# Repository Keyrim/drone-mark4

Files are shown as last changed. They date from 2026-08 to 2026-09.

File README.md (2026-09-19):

# drone-mark4 - "throw-drone"






A 5-inch racing drone is thrown by hand, motors off. The firmware detects the
throw, predicts the apex of the parabola, spins the motors up ahead of time,
recovers from an arbitrary attitude (the drone may tumble) and settles into a
stable hover. Everything is rewritten from scratch - firmware, simulator,
tooling - as a deliberate learning project. Behavioral reference: ArduPilot's
"Throw Mode".

Documentation:

- [API reference](https://keyrim.github.io/drone-mark4/) - Doxygen over the C++ of every node plus these pages, published from `main`
- [docs/architecture.md](docs/architecture.md) - system architecture (diagrams)
- [docs/plan-dev.md](docs/plan-dev.md) - development plan and reference document
- [docs/contributing/cpp-guidelines.md](docs/contributing/cpp-guidelines.md) - C++ coding guidelines
- [docs/mobile-app.md](docs/mobile-app.md) - phone as gateway: what the two mobile PoCs established, and the roadmap of `software/mobile`
- [docs/comm-design.md](docs/comm-design.md) - communication stack: transport presence, messaging postman, pull discovery, and the services on the messenger (issues #29 and #31)
- [worktrees/README.md](worktrees/README.md) - git worktrees: where they live, how to bring one up, build it, open it, remove it

## Modules

- `flight-core/` - pure flight core: no dynamic allocation, no
  exceptions/RTTI, no clock access. `float` everywhere
  (`-Wdouble-promotion` as an error).
- `platform/` - 3 abstract services (AbsSensorSource, AbsMotorSink,
  AbsClock) plus one implementation set per variant; commands come in
  through the `messaging` component, not through a platform service. No singletons: each executable has an
  explicit composition root in its main.
- `protocol/` - one protobuf schema (`mark4.proto`), codecs generated at
  build time for C/C++ (nanopb) and GDScript (godobuf); spoken by
  everyone (firmware, sim, Godot, hub).
- `telemetry/` - the registry of named measures a node exposes, declared
  next to the variables they read. A leaf: names, units and pointers, no
  wire. A ground tool discovers the list and streams the subset it wants.
- `transport/` - the interface manager: frames every payload with a source
  and a destination node, learns every node it hears, relays between links.
- `log/` - one logging module per source file, filterable at runtime, its
  lines going out on the wire like everything else.

## Build

### Inside the devcontainer (recommended)

Open `drone-mark4.code-workspace` in VS Code -> "Reopen in Container". The
workspace exposes the repo root and `software/` (the CMake project root) as
folders and carries the debug configurations. Both toolchains (native gcc +
arm-none-eabi) and the pinned tooling live in the image.

```sh
# Desktop: build + tests
cmake --preset desktop && cmake --build --preset desktop && ctest --preset desktop

# Sanitizers (ASan/UBSan)
cmake --preset desktop-san && cmake --build --preset desktop-san && ctest --preset desktop-san

# STM32F405 cross-compilation (Cortex-M4F) -> firmware.elf
cmake --preset stm32 && cmake --build --preset stm32

# Sign of life (runs its loop with or without a plant, no frame limit by default)
./software/build/desktop/drone_sim/drone_sim
```

### Mobile app (Flutter, Android)

`software/mobile/` is the Flutter project; the image carries Flutter, the
Android SDK, the NDK and adb. The phone is reached over Wi-Fi (developer
options -> wireless debugging), the container being on the host network:

```sh
./scripts/adb_wifi.sh                     # discovers the phone over mDNS, pairs once, connects
cd software/mobile && flutter pub get && ./tool/gen.sh   # generated codec, wire hash
flutter run                               # or: flutter build apk --debug --target-platform android-arm64
```

### Manual build (outside the container)

Prerequisites: CMake >= 3.25, Ninja, gcc, arm-none-eabi-gcc (ARM tarball
14.2.rel1), clang-format/clang-tidy 21 for the checks. Same commands as above.

### Code quality

```sh
git ls-files '*.cpp' '*.hpp' '*.c' '*.h' | xargs clang-format --dry-run --Werror
run-clang-tidy -p software/build/desktop "$(pwd)/(apps|flight-core|platform|protocol|tests)/"
```

## Simulation chain

Three processes are transport nodes on udp/47820 and find each other by
the transport's keepalives; the plant and the hub then ask every node that
appears who it is. The Godot plant spawns one virtual drone per node that
answers `drone_sim` and feeds it sensor frames in lockstep, `drone_sim` answers with
actuator frames and streams its status, logs and telemetry to the nodes
that subscribed, the hub decodes it for the pages. Nothing is configured,
start them in any order.

```sh
# Terminal 1 - flight process (one per virtual drone wanted)
./software/build/desktop/drone_sim/drone_sim

# Terminal 2 - the plant (the desktop build generated its codec)
godot --path sim-godot

# Terminal 3 - decoding endpoint and web pages on http://127.0.0.1:47810
./software/build/desktop/hub/hub
```

Every python tool in the repository runs on the standard library alone, so
there is nothing to install first.

## Debugging from VS Code

`drone-mark4.code-workspace` provides:

- `drone_sim (gdb)` - debugs the CMake launch target: pick the `desktop`
  preset and the `drone_sim` target in the CMake Tools status bar, the
  target is rebuilt automatically before each launch;
- `sim_stub (python)` - streams frames until stopped.

The default build task (Ctrl+Shift+B) builds the active CMake configure
preset.

## CI

- `devcontainer-image.yml` - reusable workflow that tags the image by a hash
  of the Dockerfile, builds and pushes it to GHCR
  (`ghcr.io/keyrim/drone-mark4-devcontainer`, public) only when that tag is
  missing, and retags `:latest` on main.
- `ci.yml` and `docs.yml` each call it as a first `image` job and run every
  other job inside the digest it returns, so a Dockerfile change is built and
  tested inside the PR that makes it, with no digest to bump by hand. `ci.yml`
  has 8 parallel jobs: desktop+tests, stm32, esp32, desktop-san, pages,
  mobile (gen, flutter analyze, format, test, debug apk), clang-format+ascii,
  clang-tidy.

## J-Link license note

The development image downloads the J-Link tools from segger.com: the
automated download (`--post-data accept_license_agreement=accepted`) implies
acceptance of the [Segger license](https://www.segger.com/downloads/jlink).
If that is a problem, comment out the J-Link layer in the `Dockerfile` or
install the .deb manually. The whole J-Link stack (`JLinkExe`,
`JLinkGDBServer`, `JLinkRTTClient`) runs inside the container: the probe is
attached to WSL with `usbipd` and reaches the container through the `/dev`
bind mount (see `docs/bring-up.md`).

## License

[MIT](LICENSE).

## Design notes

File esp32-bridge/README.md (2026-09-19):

# ESP32 relay

Firmware for the ESP32-C3 SuperMini (IPEX variant) riding the drone, wired
to the flight controller's UART. It is a transport relay
(`software/components/transport/`): one transport node with two links, the
board's UART and the WiFi LAN, forwarding frames between them. It is a node
of the system like any other: present on both links through the
transport's keepalive, answering an `IdentityRequest` with its own
`Announce` like every other node, and it logs through the
project's log library. From the LAN's point of view the board and the relay
are two nodes on udp/47820 sharing one address, exactly like `drone_sim` is
one; the hub has no path, port or click specific to either. It updates
itself over the air from the hub's update panel, like the flight
controller does (see "Over-the-air update" below).

## What crosses, and what does not

The relay forwards with the transport's generic rules alone (split
horizon, one hop less per relay, duplicate drop by `(src, seq)`); every
transport node relays, and this one is the only node with two links:

- towards the LAN: everything the board emits (its `Status` stream, its
  telemetry samples, its log lines, its answers), each a unicast to the
  node that asked or subscribed, plus its keepalives;
- towards the UART: every unicast the transport routes there (the board is
  the only node on that link, so a unicast routed there is for it: RC,
  tuning, subscriptions, updater messages), and the LAN's keepalives, which
  are the only broadcasts left. The line is 921600
  baud and `UartStream::write` refuses a frame the TX ring cannot hold
  whole, so a LAN that sends the board more than the line carries degrades
  by dropping, never by blocking.

What the relay says itself travels the same way: its keepalive is a
broadcast on both links like any node's, its log lines and its module
table go to whoever asked for them.

Nothing relayed is decoded. What the delivery hands to the relay itself
goes to its `Messenger` (`software/components/messaging/`), which decodes
it once and calls the one handler that claimed its body tag; a message no
handler claimed is counted and dropped. Four handlers claim something
here: `LogProvider` (the line subscription, the module table, the level
moves), `Commands` (`Reboot`), `Discovery`
(`IdentityRequest`) and `OtaProvider` (the six `Ota*` requests).

## Composition

`main/bridge_main.c` brings the network up (unchanged: STA on the network
named in `local.cmake`, or the `mark4-bridge` access point after ten seconds
without an address) then hands over to `relayRun()` in `main/relay.cpp`:

- `UartStream`, an `AbsByteStream` over the ESP-IDF UART driver rings
  (`uart_read_bytes` with a zero timeout, `uart_write_bytes` only when the
  transmit ring has room for the whole frame, refused and counted
  otherwise), wrapped in the shared `UartLink` (serial framing
  `A5 5A len16 payload crc16`);
- the shared `UdpLink`, compiled as is against lwIP's BSD socket API
  (shared discovery port 47820 with `SO_REUSEADDR`, ephemeral data socket,
  broadcast to 255.255.255.255 with `SO_BROADCAST`). lwIP has no
  `getifaddrs()`; the relay hands its own address to
  `UdpLink::addLocalHost()` so its broadcasts coming back are dropped as
  echoes;
- `Transport` with node id `hashNodeId()` of the WiFi MAC; it relays
  between its two links as any transport node with several links does;
- the shared `Messenger` over it: the one caller of `Transport::poll()`,
  the one decoder and the one encoder of this node;
- `LogProvider` (`software/components/log/`), this node's log on the wire:
  the lines to whoever subscribed, the module table one page per request,
  the levels;
- `Commands`, the handler of what is left of the node's own: the `Reboot`
  that ends an update session, announced on the radio before the reset;
- `Discovery` (`software/components/discovery/`) with the identity built
  by `relayIdentity()`: kind `RELAY`, name `relay-<the low three bytes of
  the WiFi MAC>`, mcu `ESP32C3`, the build epoch and short commit hash the
  top-level `CMakeLists.txt` stamped in, and the wire hash. It answers an
  `IdentityRequest` and nothing else: this node asks nobody who they are,
  so it carries no directory;
- `FirmwareStoreEsp32` (`main/firmware_store_esp32.cpp`) over the two OTA
  partitions and the shared `OtaUpdater` (`ota/updater.hpp`) on top of it,
  served on the wire by the shared `OtaProvider` (`ota/provider.hpp`) over
  a `RelayOtaGate` that arms
  nothing and watches no pack voltage: the update session, fed by the
  `Ota*` unicasts a hub addresses to the relay. A flash that is not laid
  out for two slots leaves the provider unbuilt, so no handler claims the
  `Ota*` tags at all and every request is refused;
- the log library: the shared `ConsoleSinkPosix` (its console is plain
  stdio) next to the `LogProvider` above, the two sinks every line goes
  to. The clock is `esp_timer_get_time()`. The bring-up in `bridge_main.c` is C and
  speaks through two shims, `bridgeLogInfo()` / `bridgeLogWarn()`, rather
  than being ported to C++: the smaller diff of the two.

The main task polls the messenger once per FreeRTOS tick (1 ms,
`CONFIG_FREERTOS_HZ=1000` in `sdkconfig.defaults`): one frame is one
datagram, no aggregation. Every poll drains both links whole; a 160-byte
telemetry frame takes 1.7 ms on the line, so the added latency is under one
frame time either way. The UART driver keeps 4096 bytes on the way in
(about 44 ms of a full line, what a WiFi stall may cost before bytes are
lost and the framing resynchronizes) and 1024 on the way out.

The shared sources are compiled by the ESP-IDF build straight from
`software/components/`: `transport.cpp`, `uart_link.cpp`,
`posix/udp_link.cpp`, `messaging/src/messenger.cpp`,
`discovery/src/discovery.cpp` (the answer alone: `discovery_directory.cpp`
stays out, this node asks nobody), the log library (`module.cpp`,
`wire.cpp`, `provider.cpp`, `posix/console_sink_posix.cpp`) and the
header-only `ota/` bricks in the `main` component, the nanopb runtime,
`envelope.cpp` and the codec generated from
`software/components/protocol/mark4.proto` in `components/mark4_proto/` (same generator, same pinned nanopb commit, same
`PB_NO_MALLOC PB_BUFFER_ONLY` as the desktop build; the generator needs a
python with `protobuf` and `grpcio-tools`, the component uses the first of
the IDF interpreter and `/usr/bin/python3` that has them). The `main`
component carries the project's warning set (`-Wall -Wextra -Wconversion
-Wdouble-promotion -Werror`) and `-fno-exceptions -fno-rtti`.

## Logs

Five modules, ids from `main/log_modules.hpp` (256 up, the shared code
takes its own from `log/module_ids.hpp`): `app/boot`, `app/wifi`,
`relay/core`, `relay/stats`, `relay/ota`; the firmware store logs as the
shared `ota/store`. Every line goes to the USB Serial/JTAG console
(115200) and, once a node has subscribed to this one's lines, onto the LAN
as a `Log` envelope addressed to it. What a healthy relay prints:

```
00:00:01.712 INFO app/wifi: joined <ssid> as 192.168.1.31   (or: access point mark4-bridge)
00:00:01.760 INFO app/boot: boot: node ff42bd55 relay build 1756512000 953448a1 wire 4f2c81de
00:00:01.760 INFO app/boot: uart 921600 baud, lan data port 60278, discovery port 47820
00:00:02.140 INFO relay/core: node 6c41b2f0 up on the uart              (the board)
00:00:02.900 INFO relay/core: node 1cd5e199 up on the lan at 192.168.1.13:41283   (the hub)
00:00:12.010 INFO relay/core: node 1cd5e199 gone                        (3 s of silence)
```

`relay/stats` is the five-second counters line, at DEBUG so it is off by
default; a client turns it on with a `LogSetLevel` carrying the id of
`relay/stats` and `DEBUG`, addressed to the relay's node id (the hub's
pages list its modules like any node's), and it starts arriving as `Log`
messages:

```
00:00:20.000 DEBG relay/stats: nodes 2, relayed 1063, dropped 0, uart tx full 0
```

`relayed` counts frames forwarded (one per link for a broadcast),
`dropped` the transport's drops (unknown destination, hops exhausted),
`uart tx full` the frames the UART ring could not take whole. The timestamps are the module's uptime.

## Network

The network to join is named in `esp32-bridge/local.cmake`, which is untracked
because credentials belong to whoever builds:

```cmake
set(BRIDGE_STA_SSID "my-network")
set(BRIDGE_STA_PASSWORD "my-password")
```

Without that file the relay is an access point (`mark4-bridge`, WPA2,
192.168.4.1, see `bridge_main.c`) and nothing else. Either way the only port
in play is udp/47820, the transport's discovery port; the relay's data
socket takes an ephemeral port that the hub learns from the board's frames.
A station that loses its network keeps asking to join it back, and the
`UdpLink` tries the global broadcast again on every send, so a network that
comes back is used again without a reset.

## Wiring

| ESP32-C3 | Flight controller  |
| --- | --- |
| GPIO3 | UART TX (board out)|
| GPIO4 | UART RX (board in) |
| GND | GND |
| 5V | UART connector +5  |

921600 baud, 8N1, no flow control. The console stays on the USB Serial/JTAG
port of the module, which is why `sdkconfig.defaults` moves it off the UART
pins.

## Build and flash

The dev image ships ESP-IDF (see `.devcontainer/Dockerfile`); `idf.py` is on
the PATH and needs no `source export.sh`. From the repository root:

```sh
idf.py -C esp32-bridge build                       # -> build/esp32_bridge.bin and .ota
idf.py -C esp32-bridge -p /dev/ttyACM0 flash monitor
idf.py -C esp32-bridge fullclean                   # wipe build/
```

The build identity the boot line reports (build epoch, short commit hash)
is read by CMake at configure time, so a plain rebuild keeps the previous
pair; `idf.py -C esp32-bridge reconfigure` refreshes it. The same pair is
stamped into the image as `PROJECT_VER` (`<buildEpoch>-<gitHash>`, the
version field of the ESP-IDF application description) and into the
manifest of `build/esp32_bridge.ota`, the bundle the hub sends: the
identity a slot reports and the one a bundle announces are the same value.

The USB flash is needed once per module, to lay the flash out
(`partitions.csv`: `nvs`, `otadata`, `phy_init`, then the two application
slots `ota_0` and `ota_1` of 1984 KB each on the 4 MB flash) and to put the
first image in `ota_0`. Every later image arrives over the air.

`fullclean` keeps `sdkconfig`, so a change to `sdkconfig.defaults` only lands
after `rm esp32-bridge/sdkconfig` (or `idf.py -C esp32-bridge set-target ...`
for the target itself).

`sdkconfig.defaults` pins the `esp32c3` target, the console, the tick rate,
the 4 MB flash, the custom partition table and the bootloader's rollback,
and is the only tracked configuration; `sdkconfig` and `build/` are
generated. The port is whatever the board enumerates as once attached to WSL
with `usbipd` (`/dev/ttyACM*` for the native USB serial of the C3,
`/dev/ttyUSB*` behind a USB-serial chip).

## Using it from the hub

Nothing to do: the board shows up in the hub's discovery like `drone_sim`
does, and the Connect button of its row is the same. The relay sits next to
it as a `relay` node at the same address: nothing to click, a place to read
its logs and turn `relay/stats` on.

## Over-the-air update

The relay runs the update system of `docs/ota-design.md` (section 8) as
one more node: the same `OtaUpdater` as the flight controller, the same
`Ota*` messages, the same hub panel. What differs is underneath and is the
store's business (`main/firmware_store_esp32.cpp`):

- the two slots are the `ota_0` / `ota_1` partitions (slot A / slot B),
  and in place of the flight controller's metadata log the store reads and
  writes what the ESP-IDF bootloader keeps in `otadata`: a staged image is
  `esp_ota_set_boot_partition()`, the self-confirmation of a trial image on
  its first ground contact is `esp_ota_mark_app_valid_cancel_rollback()`,
  a revert points the bootloader at the other slot. With
  `CONFIG_BOOTLOADER_APP_ROLLBACK_ENABLE` the IDF bootloader boots a new
  image exactly once as pending-verify and rolls back on the next reset if
  it was never confirmed: the one-shot trial of the design, implemented by
  IDF;
- the image is a raw ESP-IDF application image, verified before staging
  with IDF's own `esp_image_verify()` and matched against the announced
  length; its identity is the `PROJECT_VER` above;
- the bundle holds one image for both slots (an IDF image is
  position-independent across OTA partitions), packaged by
  `scripts/make_ota.py --esp32` at the end of every build.

From the hub's update panel: pick the relay node, type the bundle path
(`esp32-bridge/build/esp32_bridge.ota`, the default being the flight
controller's bundle) and click update. The erase of a 1984 KB slot takes a
few seconds, in 64 KB blocks with a yield between two so the task watchdog
stays quiet; the relay relays nothing meanwhile, which the design accepts
(the drone is on the ground when its radio gets reflashed). The transfer
runs over UDP directly, so the UART budget does not apply: a 870 KB image
is on the far side in seconds. The relay then answers the `Reboot`,
`relay/ota` logs the request, and the new image comes up; the first
`OtaStatusRequest` it serves confirms it.

A relay still on the old single-app layout logs `no two-slot partition
table` at boot and relays as before; it needs the USB flash above once.

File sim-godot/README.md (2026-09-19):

# Godot simulator

Standalone Godot 4.4 project (GDScript only) that plays the role of the
drones and their environment: rigid bodies with a motor model, realistic
sensor models, and a transport node that talks to the flight processes. It
runs on the HOST, not in the devcontainer, and it never links flight-core:
it only speaks the wire of `software/components/protocol/mark4.proto`,
through the GDScript codec the desktop build generates into `scripts/gen/`,
inside the frames of `software/components/transport/` (see "Transport").

The plant is one node of the LAN, kind `plant`, and hosts **one virtual
drone per `drone_sim` node it hears**: a flight process that starts is
heard, asked who it is, and gets a drone spawned on the ground for it once
its identity says `DRONE_SIM`; a flight process that dies has its drone
removed once its node expires. Each virtual
drone sends what an IMU and a barometer would measure to its own flight
process, receives the four motor commands that process decides, and
applies them as forces. Nothing else crosses the boundary.

## Run

1. Install Godot 4.4 or newer (standard build, no C# needed). The project
   already selects Jolt Physics and a 500 Hz physics tick, there is nothing to
   configure. It also pins the engine's worker pool to one thread
   (`threading/worker_pool/max_threads`): Jolt dispatches every step to that
   pool, and at 500 steps per second the wake-ups of a dozen threads cost
   more than the step itself (about 750 us against 85 us per step on a 12
   core host, the difference between 30 and 60 fps with one drone).
2. Start one flight process per drone wanted, in the container, in any
   order relative to this project (each one is a transport node on
   udp/47820 and keeps alive once per second):

   ```sh
   ./software/build/desktop/drone_sim/drone_sim
   ./software/build/desktop/drone_sim/drone_sim   # a second drone, optional
   ```

3. On a fresh clone, import the project once so Godot generates its cache
   (`.godot/` is not committed; without it the global script classes are
   unknown and every script fails to parse). Opening the project in the
   editor does it too.

   ```sh
   godot --path sim-godot --headless --import
   ```

4. Run the simulator. The Godot binary is both the editor and the runtime;
   the command line decides which one you get:

   ```sh
   godot --path sim-godot        # run the main scene directly, no editor
   godot -e --path sim-godot     # open the project in the editor (F5 to run)
   ```

The overlay is four cards around the view. Top left, the plant: its node
id, the wire hash this build speaks, how many drones it hosts, the frame
rate. Top right, the drones, one row each (flight process node id, phase,
altitude); the followed one is highlighted and a click on a row follows
it. Along the
bottom, the followed drone: its phase as a colored pill, the node id of
its flight process, the simulated time, the four motor commands as bars
(the marker on each bar is the effective speed after the motor lag), the
altitude, the accelerometer magnitude in g, the throws detected, the IMU
and barometer validity, the RC link state, and the packet counters of the
link. Bottom right, the camera mode and the keys. A toast announces a
flight process joining or leaving. With no flight process on the LAN the
world is empty and the overlay says so.

The phase, the throw count, the validity flags and the RC state come from
the `Status` each flight process streams to this plant because the plant
subscribed to it, and which the plant reads (and nothing else: it acts on
none of it). A drone that has not reported for a
second shows `no status`. The same phase colors the status light on the
rear of each drone model, which blinks while the flight process reports
its RC fail-safe active; a ring on the ground marks the followed drone,
and every drone leaves a fading trail of the last three seconds of its
path in the air.

Every sensor frame also carries the exact state (attitude, position,
velocity, no sensor model) as `PlantTruth`; the flight process forwards it
inside its telemetry, so the attitude page served by the hub draws the
estimated attitude against the exact one, per drone. Wire vectors use the
drone frame convention of the wire (body x forward, y left, z up); the
remap from the Godot axes happens in `sim_link.gd`.

## Controls

The keys and the mouse only drive the view: which drone is looked at, and
from where.

| Input | Effect |
| --- | --- |
| `TAB` | follow the next drone, in spawn order |
| click | follow the drone under the cursor |
| `C` | next camera mode |
| wheel | zoom the chase and follow cameras |
| `ESC` | quit |

Four camera modes, cycled with `C` and remembered per drone:

- **chase**: trails the drone from a fixed world offset. The offset is in
  world axes on purpose, so the view stays readable while the drone
  tumbles: the mode for a throw.
- **follow**: behind and above the drone, aligned on its heading (yaw only,
  never its roll or pitch): the third person view of a piloted flight. A
  drone entering a piloted phase pulls a chase camera into this mode once,
  unless a mode was chosen by hand for it.
- **los**: the camera stands where a pilot would (a fixed spot on the
  ground, 7 m back at eye height) and turns to keep the drone in sight,
  its field of view tightening with the distance: what a line of sight
  flight actually looks like.
- **fpv**: rides the drone, tilted up like a flight camera.

Nothing here touches a drone. This project is the plant, and it holds no
pilot state at all: the kill switch, the arm switch and the throttle are
RC, they belong between the cockpit and the flight process, and they never
pass through here. Resets and throws are scenarios (next section) that the
console page served by the hub and the mobile app send to the flight
process, which forwards them to its drone here: one door for the console
and the phone, and no key of this project on the body.

Piloting flows through the hub or the phone: an `rc` message aimed at
`drone_sim` is the same packet and fail-safe a real flight uses (200 ms of
silence trips the kill), which is exactly the path worth exercising. When
the kill switch is engaged the flight process answers with four zeros and
the motors spin down with their normal lag.

## Scenarios

A scripted run arrives as a `SimScenario` envelope, unicast by the flight
process to this plant: the flight process received it from the hub,
its messenger handed it to its plant link, and the plant forwards it to
the virtual drone that belongs to it, as its own message. One scenario is one run. It opens with a
reset - teleport, reseed every generator, clear the hand - and everything
it asks for afterwards
(the throw, or the grab and the swing) is scheduled from that reset tick, on
this project's own tick grid. Nothing outside has to agree on which absolute
tick a run began at, and nothing carries over from the run before.

A block is played once per change of its `sequence` byte, so a sender may
resend it freely: the lockstep handshake already guarantees the block gets
here, since a tick is not complete until its reply arrives.

## Physics

- Mass 0.65 kg, inertia set by hand to (0.0023, 0.0040, 0.0023) kg*m^2 in the
  body frame (y up), damping disabled, sleeping disabled.
- Four motors on a 45 degree X layout, 0.08 m from the center of mass,
  numbered like a 4 in 1 ESC: 0 rear right, 1 front right, 2 rear left,
  3 front left. Diagonal pairs spin in opposite directions.
- Each motor follows its command through a first order lag of 25 ms, then
  produces `6.0 N * w^2` of thrust along the body y axis and a yaw reaction
  torque of `0.012 N*m * w^2`, with `w` the lagged command in [0, 1]. Four
  motors at full speed give 24 N against 6.4 N of weight, about 3.7:1.
- A linear air drag of `-0.05 N/(m/s) * v` keeps ballistic trajectories
  plausible without pretending to model a real drag polar.
- An instant throw is a constant force applied for 120 ms (the exported
  `throw_duration_s`), sized so the velocity increment matches the release
  velocity of the scenario, plus an angular momentum impulse for its release
  spin. Gravity keeps acting during those 120 ms, so the release velocity is
  slightly lower than the requested increment. Nothing is faked in the
  sensors: the thrust phase and the free fall that follows are what the
  rigid body actually does.

## Sensors

Sampled once per physics tick, in this order for every channel: ideal value,
constant bias, gaussian noise, clipping to the full scale, quantization to the
LSB of a 16 bit converter.

- **Accelerometer**: specific force in the body frame, not coordinate
  acceleration. It is computed from the velocity delta of the physics step,
  `f = (v - v_previous) / dt - g`, rotated into the body frame. Contact forces
  are therefore included for free: the reading is +1 g upward while sitting on
  the ground, exactly 0 in free fall, and a few g while the hand accelerates
  the drone. Full scale +/- 16 g.
- **Gyro**: body angular rates, full scale +/- 4000 deg/s, which a tumbling
  throw can approach.
- **Barometer**: standard atmosphere,
  `p = 101325 * (1 - 2.25577e-5 * h)^5.25588`, plus noise.

Noise standard deviations, bias spread and the generator seed are exported on
the `Sensors` node. The generator is seeded explicitly and the biases are drawn
once at startup, so the same seed replays the same sensor stream.

## Transport

`scripts/transport/transport.gd` (`Mark4Transport`) is the GDScript port
of `software/components/transport/`, the same frames and the same rules:
an 11-byte little-endian header (`src u32, dst u32, seq u16, flags:hops
u8`, the hop count on the low nibble and the keepalive flag on bit 7)
in front of every payload, a node table learnt from every frame heard
(address, last sequence, boot id, received / lost / duplicate counters,
3 s expiry, `node_up` / `node_down` signals), presence as a keepalive - a
flagged frame carrying the sender's boot id, broadcast every second and
unicast once to every newcomer, never delivered upward whatever it carries
- duplicates dropped by `(src, seq)`. A keepalive whose boot id is not the
one held is another run of the same node id: the transport takes that node
down and up again, so the drone it hosts starts over instead of believing
it is still subscribed. An empty payload handed to `send()` is refused. No
relay, so every frame it sends carries `hops` 0.
The node id is a random nonzero `u32` drawn at start.

Sockets, as in the C++ `UdpLink`: one shared discovery socket on
udp/47820 (`--discovery-port N` after `--` for an isolated pair) that receives
the broadcasts of the LAN, and one ephemeral data socket every frame
leaves from, so its source port is this node's unicast address. Godot's
`PacketPeerUDP.bind()` sets no reuse option and refuses a port another
process already holds, so the discovery socket is a `UDPServer`: its
`listen()` sets `SO_REUSEADDR`, which Linux honours for UDP next to the
`SO_REUSEADDR + SO_REUSEPORT` pair the C++ link sets, and the hub, the
flight processes and this plant share udp/47820 on one host. The server
hands datagrams out as one `PacketPeerUDP` per remote address; the
transport keeps them and drains them all on every poll. Broadcasts go to
`255.255.255.255`, and to `127.255.255.255` when the host has no route
for the former, like the C++ link.

`scripts/transport/announce.gd` builds this plant's identity (an
`Announce` of kind `PLANT`, name `godot-plant`, mcu `SIM`, the wire hash of
the generated codec) and keeps the body tags a payload is told apart by,
after one look at its first bytes: every payload addressed to this node
goes through one handler, the lockstep actuator frames of every drone it
hosts at 500 Hz included, and the codec never runs on a frame it does not
want.

`scripts/transport/discovery.gd` (`Mark4Discovery`) is the GDScript port
of `software/components/discovery/`, both directions of "who are you":
every node the transport learns is asked with one `IdentityRequest`, sent
again every 500 ms up to 5 times before the node is left mute, and the
`Announce` that comes back is kept as that node's identity and reported on
the `identity` signal; an `IdentityRequest` addressed to this plant is
answered with its own `Announce`, unicast to whoever asked. Nothing is
broadcast and nothing is unsolicited: presence is the transport's
keepalive, identity is asked for.

`scripts/transport/requests.gd` (`Mark4Requests`) is the port of the
request side of `software/components/messaging/`, the one place this node
numbers, resends and acknowledges. A message that has to arrive travels as
a request: it carries a `request_id` of this node's own counter (field 100
of the `Envelope`, never 0), it is kept encoded and sent again every 500 ms
up to 5 sends by default (the policy is per call), and the `RequestAck`
carrying the same id completes it; out of sends, or when the destination
goes down, the request is dropped and `request_failed` says so. The other
direction is automatic: every payload this plant receives that carries a
non-zero id is answered with a `RequestAck` at once, whatever it is and
whether or not anything here reads it. That answer is built from the first
bytes of the payload, so it costs no decode and does not depend on the
order the listeners of `payload_received` were connected in. Stream data
(the `Status`, the lockstep frames) carries no id and is never
acknowledged: a sample is only worth its own instant.

`scripts/transport/status_consumer.gd` (`Mark4StatusConsumer`) is the
consumer of that stream. A flight process emits its `Status` to the nodes
that asked for it and to nobody else, so the plant sends one
`StatusSubscribe { enabled: true }` per drone it spawns, as a request, and
reads the answer the flight process sends back: the same message as
applied, `enabled` false when it has no room for one more subscriber. The
drone that leaves the world is told to stop the stream, unless its node is
already gone, in which case it forgot its subscribers when it left. There
is nothing to configure in the subscription: what the stream carries and
how often it comes are states of the flight process.

`scripts/drone_manager.gd` (`DroneManager`, the `Drones` node of the main
scene) owns the transport, the request helper and the directory and drives
the three once per physics tick, before the drones run. An identity of
kind `DRONE_SIM` spawns `scenes/drone.tscn` for that node, on a 1 m grid
(four per row), and subscribes to its `Status`; every payload from a known node goes to that drone's `SimLink`; a
node that expired has its drone freed 3 s later, unless it comes back
before. A flight process that restarts draws a new node id, so it gets a
new drone next to the old one's spot while the old one leaves. The plant
only ever decides on the `Announce` kind, never on an address.

The wire is `software/components/protocol/mark4.proto`, the source of
truth for every consumer. The GDScript codec is generated from it by the
desktop build (target `proto_gd`, run by `cmake --build --preset desktop`;
`godot` must be on the PATH) into `scripts/gen/mark4.gd` and
`scripts/gen/wire_hash.gd`, both gitignored: a fresh checkout has to run the
desktop build once before this project can talk to anything.
`scripts/sim_link.gd` (one per virtual drone), `sim_codec.gd`,
`announce.gd`, `discovery.gd`, `requests.gd` and `status_consumer.gd` are
the only scripts that touch the wire. Every payload is one `Envelope`:

- `SimSensor`, virtual drone to its flight process, unicast: timestamp in
  microseconds, gyro [rad/s], accelerometer [m/s^2], pressure [Pa], reset
  count, lockstep timeouts, and the exact state as `PlantTruth`. Sensors
  only: the pilot state is not a sensor reading and travels out-of-band. A
  restarted plant is recognized by its clock starting over, and by its new
  node id.
- `SimActuator`, flight process to its virtual drone, unicast: echoed
  timestamp and the 4 motor commands in [0, 1].
- `SimScenario`, flight process to its virtual drone, unicast: the run to
  play, once per scenario, taken once per change of its `sequence`.

Payloads that decode to anything else are counted as dropped and ignored;
the flight process's own `Announce`, unicast in answer to the plant's
question, is not counted. Motor commands are clamped to [0, 1] on arrival.
No port is configured anywhere: the flight process answers to the node the
sensor frame came from, and the plant asked the flight process who it
was.

`scripts/sim_codec.gd` (`SimCodec`) writes the SimSensor and reads the
SimActuator by hand, straight into bytes: the generated codec builds an
object tree per message and costs about 200 us to encode a SimSensor and
130 us to decode a SimActuator, which at 500 Hz per drone decided the frame
rate of the whole simulator. The hand-written pair costs a few microseconds
and produces the same bytes; `tests/plant_link_check.gd` sends and reads
through it so the nanopb side of the unit tests checks it. Everything else
(Announce, Status, SimScenario) is rare and keeps the generated codec.

Cost: one exchange (codec plus header plus send) is about 45 us of GDScript
per drone per tick on a desktop core; the reply costs about as much to
read. The transport header and the node table add a few microseconds.

The timestamp comes from the physics tick counter divided by the tick rate,
never from a wall clock. If the host cannot keep up with 500 Hz the stream
slows down but stays continuous and reproducible.

## Lockstep

`SimLink` has a `lockstep` flag, off by default (`--lockstep` after `--`
turns it on for every drone). When it is on, the physics tick sends its
sensor frame and then pumps the transport, sleeping 20 us between polls,
until the actuator frame echoing that very timestamp arrives or
`lockstep_timeout_ms` (default 50 ms) expires, resending the frame up to 20
times; then the previous motor commands are reused and the counter shown
in the overlay increases. With several drones the ticks are serialized:
each one waits for its own flight process in turn.

This blocks the main thread, so the window stops repainting while it waits. It
is meant for deterministic runs and for stepping through the flight process in
a debugger, not for comfortable flying. Off, the simulator never waits: the
replies are drained at the beginning of the next tick, which costs one tick of
latency and is closer to what a real vehicle experiences anyway.

## End to end smoke test

In the container:

```sh
cmake --build --preset desktop
./software/build/desktop/drone_sim/drone_sim
```

In another terminal, the telemetry viewer:

```sh
./software/build/desktop/hub/hub
```

then open `http://127.0.0.1:47810` for the plots.

On the host, run the Godot project, then:

1. Check that the overlay shows one drone and that its counters for sent
   and received packets both climb. Start a second `drone_sim`: a second
   drone appears on the ground next to the first; stop it: the drone is
   removed about 6 s later (3 s of node expiry, 3 s of grace).
2. At rest on the ground the accelerometer reads about 1.00 g.
3. Send a `throw` from the console page. During the throw the
   accelerometer jumps for about 120 ms, then drops to nearly 0 g for the
   whole ballistic phase, and the gyro shows the tumble; the trail draws
   the arc. The plots page shows the same rates, since both tools read the
   same flight process.
4. Engage the kill switch from the hub and check that the motor bars of the
   overlay fall to zero.
5. Send a `reset` from the console page to put the drone back on the
   ground and start again.

## Layout

The ground carries a world-space metric pattern (1 m checker, grid lines
every meter, thicker lines every 5 m) and orange pylons of known height
(1 m at the four +/-5 m corners, 2 m at 10 m out) so distances, speed and
altitude can be judged by eye. Spacing, line widths and colors are uniforms
on the ground material.

The drone model is built from primitives in `scenes/drone.tscn`: an X
frame with the front arms marked red, the stack between two plates, the
battery strapped on top, a tilted camera, the four motors with their
props. The props turn with the effective motor speeds and blur into
translucent discs as they speed up; a status light on the rear takes the
phase color of the overlay. The fonts of the overlay are vendored in
`assets/fonts/` (JetBrains Mono and Inter, both under the OFL, see the
README there); the folder is ignored by the editor and read at start, so
they need no import.

```
project.godot          engine configuration, Jolt, 500 Hz, key bindings
scenes/main.tscn        ground, pylons, sky, light, camera rig, drone manager, overlay
scenes/drone.tscn       one virtual drone: body, model, sensors, sim link, hand
shaders/ground_grid.gdshader  metric grid ground material
scripts/transport/transport.gd  the transport node: frames, node table, keepalive
scripts/transport/announce.gd   this plant's identity, the body tags read on the wire
scripts/transport/discovery.gd  who is who: identity asked of every node, and answered
scripts/transport/requests.gd   requests: numbered, resent, acknowledged on arrival
scripts/transport/status_consumer.gd  the Status stream of each drone, subscribed to
scripts/drone_manager.gd  one virtual drone per flight process heard
scripts/drone.gd        rigid body, motor model, drag, throw, tick loop
scripts/sensors.gd      accelerometer, gyro, barometer models
scripts/sim_link.gd     sensor frames out, actuator frames and scenarios in
scripts/sim_codec.gd    hand-written codec of the two per-tick envelopes
scripts/hand.gd         the simulated hand: hold, sway, swing, release
scripts/drone_view.gd   props, status light, follow ring, trail of one drone
scripts/trail.gd        the fading ribbon of a drone's recent path
scripts/phase_style.gd  colors and names of the flight phases
scripts/world_input.gd  keys and mouse of the view: next drone, pick, camera, quit
scripts/camera_rig.gd   the four camera modes
scripts/hud/hud.gd      on screen overlay (cards, drone list, toasts)
scripts/hud/hud_style.gd  fonts, colors and style boxes of the overlay
scripts/hud/motor_bars.gd the four motor bars of the overlay
scripts/sim_args.gd     command line flags after --
assets/fonts/           JetBrains Mono and Inter, vendored, OFL
tests/transport_check.gd   ctest smoke of the transport, no peer needed
tests/plant_link_check.gd  cross-language check driven by the C++ unit tests
```

godot-tools LSP: port 6005 is forwarded by the devcontainer.

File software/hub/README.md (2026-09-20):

# hub

The gateway between the transport and the browser: one transport node
(kind `gateway`, one `UdpLink`, it keeps alive like the others and relays
nothing) that decodes everything it hears and publishes it to its websocket
clients as typed messages. Nothing raw crosses: a client never sees an
`Envelope` and never sends one, it sends typed commands the gateway carries
out through one consumer. What the hub owns besides that is what a browser
cannot: the `.ota` bundle on disk, the tuning profiles on disk, and the node
table with every node's identity (asked for, kept in a
`DiscoveryDirectory`).

That same TCP port also serves the static pages: the library dispatches on
the `Upgrade` header, so a page loaded from the hub reaches it back with
`new WebSocket("ws://" + location.host)` and never learns a port of its own.

It links the `protocol` (both schemas), `transport`, `messaging`,
`discovery`, `log`, the five consumers, `ota_consumer` and `hub_core` and
nothing else: never `flight-core`, never `platform`. Desktop only. The
transport is polled through a `Messenger`, and what the gateway knows it
knows through one consumer per concept (`StatusConsumer`, `LogConsumer`,
`TelemetryConsumer`, `TuningConsumer`, `TransportConsumer`, each sized at
`Transport::MAX_NODES`). A consumer names the kinds that carry its
provider, so the gateway names none: it opens a node when the directory
learns its identity, subscribes, pulls the tables one page at a time and
drops everything of a node that goes down.

One gateway per concept sits on each consumer, one file per concept
(`gateway_status`, `gateway_log`, `gateway_telemetry`, `gateway_tuning`,
`gateway_transport`, plus `gateway_pilot`, which has no consumer behind it
because `Rc` is a stream and not a state). Each listens to its consumer,
publishes what it holds through the composition (`AbsGatewayPublisher`:
`broadcast()` and `sendTo()`), and carries out the commands of its own
concept. Two handlers
of the composition complete them: `OtaReader`, which feeds the update
consumer the `OtaStatus` / `OtaAck` / `OtaChunkAck` it waits for (that
consumer was moved as it was and is not a handler itself), and
`HubRequester`, which claims no tag and exists to own the requests a node
command sends (a reboot, a scenario). The directory is the handler of
`IdentityRequest` and `Announce`.

It logs like every node (`gateway/core`, `gateway/ws`, `app/main`
modules): on its stdout, and as `Log` lines to whoever subscribed to it. A
messenger refuses this node as a destination, so its own lines reach its
clients through the local sink of its `LogProvider`, which is the log
gateway: they appear as `NodeLogLines` from its own node id, exactly like
every other node's.

## Building and running

```sh
cmake --preset desktop && cmake --build --preset desktop
./software/build/desktop/hub/hub
```

The hub takes **no arguments**. It serves with its built-in defaults
(endpoint on 127.0.0.1:47810, transport discovery port 47820, profiles in
`profiles/`, pages in `software/hub/pages/dist` resolved from the binary
location, own name `hub-<hostname>` in the node table). A flight process
reaches it by its keepalives on the discovery port; nothing is wired by
hand, nothing is "connected": every node the transport hears is in the
table, and a page
commands whichever node id it wants. A default worth changing is a
compile-time change in `transport/udp_link.hpp` or `HubApp::Config`, not a
flag.

The hub never starts Godot or a flight process: both are yours to run and
restart at will (Godot from its own terminal or the "godot sim" VS Code
task, `drone_sim` from anywhere). Godot is one more node of the LAN, kind
`plant`, and spawns one virtual drone per `drone_sim` it hears; discovery
picks each incarnation up within a second, so the hub is the process that
stays up for the whole bench session. Two `drone_sim` are two nodes with
two ids and two widgets.

## Pages

`GET /` serves `index.html` from the pages directory, `GET /<path>` the file
at that path below it. The hub resolves `software/hub/pages/dist` from its own
location, falling back to that relative path. A missing directory is one log
line at startup and a 404 per request, never a startup failure.

The Content-Type comes from the extension (`.html`, `.js`, `.mjs`, `.css`,
`.svg`, `.json`, `.csv`, `.ico`, `.png`; anything else is an opaque byte
stream), and every response carries `Cache-Control: no-store`. A URI holding
a `..` component is refused: nothing outside the pages directory is
reachable.

## HTTP API: the telemetry store

The HTTP side stays filesystem-only, which is the invariant that keeps the
hub lock-free: these handlers run on the websocket library's connection
threads and touch no registry and no counter. They read and write files
under the telemetry directory, `logs/telemetry` resolved from the hub's own
location (the repository ignores `logs/`, so an export is bench output and
never source). The directory need not exist: the first save creates it.

| route | method | what |
|---|---|---|
| `/api/telemetry/configs` | GET | JSON array of `{name, bytes, modified}`, one per stored view config, by name. |
| `/api/telemetry/configs/<name>` | GET | the stored config document. |
| `/api/telemetry/configs/<name>` | PUT | stores it as `configs/<name>.json`. The body must parse as JSON; it is never interpreted, the shape is the page's business. Answers `{name, bytes}`. |
| `/api/telemetry/configs/<name>` | DELETE | removes it. |
| `/api/telemetry/exports/<name>.csv` | GET | serves `exports/<name>.csv` as a download (`Content-Disposition`), so a browser saves it under that name. |
| `/api/telemetry/exports/<name>.csv` | PUT | stores the CSV the page built, as it comes: the hub never parses it. |

A name becomes a file name, so it obeys one rule: 1 to 64 characters of
letters, digits, `_` and `-`. No separator, no dot, no leading dot, nothing
that could name a file outside its own directory; anything else is a 400.
Every body is capped at 64 MiB. A wrong method on an existing route is a
405, an unknown route a 404, and so is every telemetry route when the hub
was given no telemetry directory.

## Websocket contract: gateway.proto

Every websocket message, both directions, is one binary
`mark4.GatewayMessage` of `software/components/protocol/gateway.proto`
(nanopb on the hub side, `hub/gateway_codec.hpp`; protoc-gen-es on the
page side). Text frames are ignored. There is no JSON anywhere, and no
encoded `Envelope`: the types a client needs of `mark4.proto` are the ones
`gateway.proto` imports (`Status`, `TelemetryDescriptor`, `TelemetryData`,
`LogModuleInfo`, `Log`, `Announce`, `Rc`, `TuningInfo`, `TuningAck`,
`SimScenario`, `TransportReport`).

Gateway to client, the state the gateway holds: on every change, and whole
to a client that connects.

| body | what |
|---|---|
| `nodes` | `NodeTable`: identity and presence only - the gateway itself first (address empty), then every node the transport hears: id, IPv4 `address`, `port`, `last_seen_ms_ago`, and its `Announce` once the directory has it (every node that appears is sent an `IdentityRequest`, again every 500 ms up to five times; a node that never answers shows without identity). Every second and on every change. |
| `node_log_modules` | `NodeLogModules`: one node's whole module table with the level of each, as its `LogConsumer` pulled it; empty for a node that went down. The gateway's own table is published the same way, from its own registry. |
| `node_log_lines` | `NodeLogLines`: the lines of one node as they arrive, one per message, and on connect the last 256 lines the gateway kept per node, oldest first. The gateway's own lines come from its own node id. |
| `node_status` | `NodeStatus`: one node's last report, at that node's own cadence. |
| `node_telemetry` | `NodeTelemetry`: one node's whole measure table, `{id, name, unit}` per measure, as its `TelemetryConsumer` pulled it page by page. A node that goes down publishes an empty table: the ids of a table are only stable while the node runs, so a client must drop its curves rather than rebind them to whatever the next boot numbers the same way. |
| `node_telemetry_config` | `NodeTelemetryConfig`: the configuration as the node applied it (the ids it kept, the period it clamped) and whether the gateway holds its sample stream. |
| `telemetry_samples` | `TelemetrySamples`: one sampling instant, to the clients marked on that node and to them alone. |
| `node_tuning` | `NodeTuning`: one node's whole parameter table. |
| `node_transport` | `NodeTransport`: one node's own view of the wire, its last report (the transport and messenger counters, one entry per link) plus what the gateway derives from it over a sliding window: a rate per link, one edge per peer it holds (frames per second, loss, duplicates) and its own counters over the window. On every complete report, and every second for the gateway's own. |
| `transport_health` | `TransportHealth`: the verdict, `VERDICT_OK` to `VERDICT_BAD`, on every node of the table and on the system as the worst of them, with the worst edge (observer, peer, loss), the frames per second over every edge and the flag that raised each verdict. Every second. |
| `tuning_result` | `TuningResult`: the answer to a write or a read, to every client; a client correlates on the id of its own command and on the parameter id. |
| `status` | `GatewayStatus`: node id, `wire_hash` (of `mark4.proto` as built), `clients`, `rc_clients` (pilot seats held), `messages_in` (payloads the transport delivered), `commands` and `refused` (client commands carried out and refused), `dropped`. Every second. |
| `ota_state` | phase, verdict and its sentence, `target_node`, `target_slot`, the loaded bundle's identity, what the board last said (slots, running / active slot), transfer progress in bytes. |
| `profiles` | answering `LIST` and `SAVE`: the profile names on disk. |
| `profile` | answering `LOAD`: one profile, name and `TuningSet` pairs. |
| `ack` | answering any client message whose `id` is not 0: `ok`, `error`; `GatewayMessage.id` echoes the client's. Acks are broadcast to every client: a client correlates on the id it drew and ignores the rest. |

Client to gateway, every one a command the gateway carries out through one
consumer and answers with an `Ack` when `id` is set.

| body | what the gateway does |
|---|---|
| `telemetry_command` | `config { ids, period_ms }`: the configuration to the node, last writer wins between clients too (there is one configuration per node). `subscribe { bool }`: marks this client; the gateway holds the node's stream while at least one client is marked and gives it back when the last one clears or disconnects. |
| `log_command` | `refresh {}`: the module table pulled again. `set_level { module_id, level }`: one level moved, on the node named or, when that is the gateway's own id, in its own registry. |
| `tuning_command` | `refresh {}`: the parameter table pulled again. `set { id, value }` / `get { id }`: one request, answered by a `tuning_result`. |
| `pilot_input` | one `Rc` forwarded to the node named, from the gateway's own id (see below). |
| `node_command` | `reboot {}` or `scenario { SimScenario }`: one request to the node named. |
| `transport_command` | `subscribe { bool }`: marks this client; the gateway subscribes to the reports of every node while at least one client is marked and gives them back when the last one clears or disconnects. The gateway's own view is published whatever the marks say. |
| `ota_command` | `START` (bundle path, empty = the build output), `ABORT`, `REVERT`, `STATUS_REQUEST`, each naming `target_node`. The target is fixed for the whole session: while a session runs, a command naming another node is refused; `ABORT` always works. |
| `profile_command` | `LIST`, `SAVE` (name + values), `LOAD` (name), `PUSH` (name + `target_node`: one parameter write per value). Names are letters, digits, `_` and `-`. |

A client that connects gets everything: the counters, the update state,
every node's status, module table and log ring, every measure and
parameter table, and the node table. The wire mismatch of a node is not a
field: a page compares `Node.announce.wire_hash` with
`GatewayStatus.wire_hash`; the hub also logs the mismatch once (a
`gateway/core` WARN) when the directory learns the identity.

### The wire itself

The transport is a concept like the others: every C++ node carries a
`TransportProvider` that answers a `TransportSubscribe` and streams what
its transport and its messenger count once a second, and the gateway holds
one `TransportConsumer` that merges the pages of each report into one view
per node. Nothing travels unasked: the gateway subscribes only while a
client is marked through `transport_command`, so with nobody watching the
wire costs nothing.

Its own view is the exception, and it needs no wire at all: a messenger
refuses this node as a destination, so the gateway walks its own provider's
pages with `fillPage()` and hands each of them to its consumer's
`accept()`, exactly as the wire would have delivered them. That view is
always held, which is why a client sees a verdict even with no node marked.

What the gateway adds is the window: the last ten reports of a node, the
newest read against the oldest, which turns cumulative counters into rates
(`NodeTransport`) and a loss per directed edge. A loss on the direction A
to B is only seen by B, so the verdict (`TransportHealth`) is read from
every view at once: the edges a node observes, the edges observed of it, a
node that hears another without being heard back, a link that refused
frames or could not deliver them whole, requests given up on, peers
expiring or restarting. `NodeTable` carries none of this any more: it is
identity and presence, and `node_transport` is what each node counts.

A percentage over a handful of frames is not a measurement, so every edge
carries the frames its window received and lost next to the ratio, and an
edge whose window holds fewer than `LOSS_MIN_FRAMES` (20) of them is quiet:
its loss enters neither `worst_in_loss` nor `worst_out_loss` and it is never
the worst edge of the verdict. Its age still counts, so a quiet edge is
judged on presence alone, which is what a keepalive is for.

### Piloting

The gateway is the pilot node: it forwards each `pilot_input` as one `Rc`
to the node named, from its own id, at the cadence the client sends. Two
rules the fail-safe depends on:

- **It never repeats.** A client that stops sending stops the stream, and
  the node's own RC timeout does the rest. The gateway holds no last state
  to resend.
- **One pilot per node at a time.** The first client to send takes the
  seat; another client's input is refused (`Ack`) while the seat is held;
  the seat is released when the holder disconnects or has sent nothing for
  `RC_PILOT_WINDOW_US` (2 s). `GatewayStatus.rc_clients` counts the seats
  held.

Simplifications, deliberate: the gateway's own Announce is sent only to a
node that asks for it (the gateway is the first entry of `nodes`, with
it); the Ack carries its id on the enclosing message only; field 1 of
`GatewayMessage` was the raw `Frame` and field 31 a gateway-level `Log`,
both reserved for good. `gateway.proto` is not part of `WIRE_HASH`: the
pages are built from the same tree as the hub that serves them.

## Firmware update

An `OtaCommand.START` sends one `.ota` bundle to the target node over the
transport, as unicasts: the updater messages are one more body of the same
envelope on the same link, so telemetry keeps flowing between them and the
ESP32 relay forwards them like any other unicast for the board. A
`drone_sim` is a valid target too, with its emulated flash.

`bundle_path` is optional and defaults to
`software/build/stm32/drone_firmware/drone_firmware.ota`, resolved from the
hub binary: the common case is one click after a build. The ESP32 relay is
a valid target too, with `esp32-bridge/build/esp32_bridge.ota` typed as the
path: its bundle holds one image for both slots (an ESP-IDF image is
position-independent across the OTA partitions) and the relay runs the same
updater over its partitions. Loading validates the bundle against itself
(magic, wire hash, announced sizes and CRC-32, and each image against the
manifest entry describing it: its `OtaImageHeader` for the STM32s and the
sim, the ESP-IDF magic for the relay) and then against the board (right
chip, an image for the inactive slot, an image that fits a slot). Only then
does a byte go out.

The session then walks one phase at a time, and every change is published as
one `ota_state` message, which is what makes a progress bar move without
anybody polling:

```
IDLE -> QUERY -> ERASING -> TRANSFER -> VERIFYING -> REBOOTING
     -> WAITING_BOARD -> TESTING -> CONFIRMED
```

The transfer is go-back-N: chunks of at most 240 bytes at strictly increasing
offsets, at most 16 in flight, one cumulative `nextOffset` acknowledgement per
window. A 500 ms acknowledgement silence resends from the last acknowledged
offset; a bounded number of those and the session fails with the offset it
died at. Chunks are paced 3 ms apart, because the hub reaches the board over
WiFi and the board over a 921600 baud UART, and the poll loop tightens to 1 ms
for the duration so that pacing is the throttle rather than the sleep.

`progress.acked_bytes` is what the board has written and is what a bar must
show; `sent_bytes` runs up to one window ahead of it and goes backwards on a
resend.

After the reboot the hub polls `OtaStatusRequest` once a second until the
board answers again, ignoring answers for the first 1.5 s (the old image can
still answer one request between the command and the reset). What comes back
decides the verdict, and the verdict is a sentence in `verdict_text`:

- the bundle's build epoch, on a slot reported `testing`: the trial boot
  worked. The image confirms itself on the first request it serves, so the
  hub keeps polling until the slot reads `valid`, which moves the phase to
  `CONFIRMED`; nothing is sent to confirm.
- the git hash it ran before: the bootloader rolled back. Phase
  `ROLLED_BACK`, and nothing is confirmed.
- neither: phase `FAILED`, saying what it found.

`REVERT` asks the board to activate its other slot and reboots it; it is
legal while a trial image runs, which is exactly when it is wanted.
`ABORT` drops the session and tells the board so its half-written slot is
released now rather than at its own timeout. Every refusal the board sends
(`DENIED_ARMED`, `CRC_MISMATCH`, ...) comes back as the sentence behind the
code, never as the code.

## Known limitations

- Acks are broadcast to every connected client rather than sent back to the
  one that asked: a client correlates the answer with the `id` it sent and
  ignores the rest. The snapshots and the sample streams do go to one
  client, so the endpoint knows its connections; the ack simply never
  needed it.
- The endpoint has no authentication. It binds the loopback interface, and
  it is a bench tool on a trusted network.
- The hub relays nothing: with one link there is nothing to relay between.
  Two hubs on one LAN both hear every broadcast and both keep alive; the
  board learns both through its relay.
- Tuned values do not survive a simulator reset: `drone_sim` rebuilds its
  flight core on the reset (there is no state a teleport could keep) and
  its identity does not change, so the hub has no event to push a profile
  on. Push
  it again explicitly with `ProfileCommand.PUSH` after resetting the world.
- POSIX only (`/proc/self/exe`, `poll`).

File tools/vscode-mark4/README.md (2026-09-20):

# vscode-mark4

Thin editor extension around the existing tooling. It adds a Mark4 sidebar
with four views, an output channel for the logs of the whole bench, and opens
the hub pages inside the editor. Everything about the running bench comes
from one websocket to the gateway (the hub, `ws://127.0.0.1:47810`): the
extension is one more client of `gateway.proto`, like the pages. Nothing
raw crosses that link: the gateway publishes typed messages (`NodeTable`,
`NodeLogModules`, `NodeLogLines`, `GatewayStatus`, `TransportHealth`) and the
extension sends typed commands (`LogCommand`), so it never encodes or decodes
an `Envelope`.

- **Apps**: one line per apps.json entry, with inline build / run / debug.
  Build and run shell out to `scripts/build_app.py` / `scripts/run_app.py`
  (the single build implementation); debug starts the workspace launch
  configuration named after the app.
- **Nodes**: one line per node of the gateway's `NodeTable`, whoever started
  it: an icon per kind (firmware, drone_sim, plant, gateway, batch, relay, a
  generic one for a kind this build does not know), the name, then the kind
  and the node id in 8 hex digits, and a warning icon plus `WIRE MISMATCH`
  when the node announces another `mark4.proto` hash than the gateway's.
  Colour and suffix say what the gateway makes of that node's transport (the
  verdict of its `TransportHealth`, published every second): green while the
  node was heard less than 1.5 s ago and the verdict is ok, yellow plus
  " degraded", red plus " bad", grey when the node is fading ("fading",
  after the verdict when both) or nothing is known of its transport yet. That
  verdict is partial while no transport page is open: the gateway subscribes
  to the reports of the other nodes only for a client that asked for them,
  and judges from its own view alone until one does. The tooltip has the
  address, the build date, the git and wire hashes, then the transport line:
  the verdict, the worst loss the node observes and the worst loss observed
  of it, and one word per flag the gateway raised (`asymmetric`,
  `requests-failed`, `fading`, `refused`, `rx-errors`, `churn`). Inline stop
  for what runs on this machine (the hub, the Godot plant, a drone_sim the
  extension started); the title bar starts one more `drone_sim` (`+`) or the
  Godot sim (globe). With no gateway the view is one line, "gateway offline:
  start the hub", with a start action. The table arrives once a second and
  almost never differs: the view is only redrawn for the lines that read
  differently (a name, a kind, live or fading, a wire mismatch, a verdict),
  and only the whole view when nodes appear or leave. The losses and the
  last-seen of the tooltip are not a reason to redraw, so they are one
  refresh behind at worst.
- **Log levels**: every module of every node with its current threshold,
  grouped by node or by module name (the title action switches). A `/` in
  the names makes a folder (`platform/`) when two modules or more share it.
  "Set level..." on a leaf, a folder or a node sends one
  `LogCommand.set_level` per module below it and then a refresh, so the tree
  shows what the nodes confirmed rather than what was asked; the same gesture moves what the log
  channel shows of that same scope, so the lines follow the level. On a
  node, "Hide / Show in logs" (eye) drops its lines from the channel and
  touches nothing on the wire. The title bar has the same gesture over the
  whole bench, "Set level for everything..." (gear): every module of every
  node of the table at once. `Mark4: Reset Levels To INFO` (command palette)
  is that same change at INFO, the level a node starts at. A node that has
  not published its module table yet has no module to set: it is skipped and
  named in the `Mark4` channel. The title bar also searches the logs
  (magnifier, an empty answer clears the search) and clears them (the store,
  not the filter), and shows the channel (`Mark4: Show Logs`, `ctrl+alt+l` /
  `cmd+alt+l`, which keeps the focus where it is). Like the nodes view, it
  only redraws the subtrees that read differently.
- **Bench**: what is not a node, the three pages to dock: control, plots and
  transport (the state of the wire seen from every node). `Mark4: Bench
  Session` (rocket icon) builds and starts the hub, starts the Godot sim,
  then docks the control and plots pages in two editor groups.

The **Mark4 Logs** output channel separates what was received from what is
shown. Every line of every `NodeLogLines` the gateway publishes is stored
raw (a ring of 50000 records: the extension's own clock at reception, the
node, the module id, the level, the text) and nothing is formatted at
ingest. A window that opens while the bench runs is given the ring the
gateway kept per node, so the channel starts on what already happened. The channel is
then the projection of that store, redrawn (at most five times a second)
whenever a node table, the display filter or the search changes; new lines
that pass are appended. The extension owns the whole line, so the columns
line up:

```
HH:MM:SS.mmm  LEVEL  kind       node id   module                    text
11:54:38.887  DEBUG  drone_sim  da532bb1  sim/link                  t=4.004 s, 2000 frames
```

Two spaces between fixed columns: the time to the millisecond, the level in
5 characters (`TRACE DEBUG INFO  WARN  ERROR`), the kind padded to 9 and
never cut, the node id in 8 hex digits, the module padded or cut to 24. The
kind is resolved at render time from the node table and the module name from
that node's `NodeLogModules`, so a node announcing late names the lines it
sent before: until then they read `unknown` and `#id`, and the next redraw
names them all. The gateway's own lines arrive from its node id like every
other node's; the state of the link itself has no node, so "reconnected to
the gateway" is stored as a line of a pseudo node `00000000` named `gateway
link` and survives the redraws like any other.

What is shown of the store is a minimum level per (node, module), INFO until
a "Set level..." says otherwise, plus a hidden flag per node and one text
search (case insensitive, over the whole rendered line: a kind, a node id or
a module name is searched like the text). Hence the one thing to know:
**lowering a level shows the stored lines at once, raising it only shows
what arrives from then on** - the node was not emitting them before, so
nothing was received to show. Nothing is persisted: closing the window
empties the store and resets the filter.

The channel is created with a language of its own (`mark4-log`, the grammar
`syntaxes/mark4-log.tmLanguage.json`), so the theme in use colors it. Color
codes the level and nothing else: one rule matches the whole line and gives
that whole line a single standard scope, picked by the level column. No
column has a scope of its own, so the kind, the node id and the module read
like the text. A line that does not hold the layout (a wrapped line, a kind
wider than its column) matches nothing and stays plain rather than being
colored wrong.

| Level | Scope | Dark+ | Light+ |
| --- | --- | --- | --- |
| `ERROR` | `invalid.illegal` | red | red |
| `WARN` | `string` | orange | dark red |
| `INFO` | none | default | default |
| `DEBUG` `TRACE` | `comment` | green grey | green |

INFO is the level a node runs at, so it is the one left plain: what stands
out is what left the normal course (WARN, ERROR) and what was asked for on
purpose (DEBUG and TRACE, dimmed).

Several `drone_sim` at once: the `+` action starts each instance with its own
emulated flash (`software/build/desktop/drone_sim/ota_flash_<n>`) and with a
node id the extension picks (`0xd500000<n>`), which is what ties the line of
the nodes view back to the task to stop. A `drone_sim` started from anywhere
else has a random id, so it is listed like any other node but offers no stop.

The pages render in webviews as full-frame iframes on
`http://127.0.0.1:47810`; the hub keeps serving them, so a browser tab still
works. If a download (recording export) misbehaves inside a webview, open the
page in a browser for that one action.

## Build and install

```sh
cd tools/vscode-mark4
pnpm install --frozen-lockfile
pnpm gen            # the TypeScript codecs, run by every script below
pnpm typecheck
pnpm test           # node:test over the pure logic
pnpm build
pnpm package        # produces vscode-mark4-0.0.0.vsix
pnpm smoke          # against a live bench, see scripts/smoke.ts
```

`pnpm gen` generates `src/gen/mark4_pb.ts` and `src/gen/gateway_pb.ts` from
the two schemas of `software/components/protocol/` with `protoc-gen-es`,
exactly as the hub pages do (same versions of `@bufbuild/protobuf` and
`@bufbuild/protoc-gen-es`, same `protoc` from the python `grpcio-tools`).
`src/gen/` is gitignored: nothing generated is committed, and the extension is
always built against the schema of the tree it sits in.

`./install.sh` keeps the installed extension equal to the sources: it runs
on folder open (the "install mark4 extension" task) and can be run by hand.
It is content-based. `source_hash.sh` hashes everything the package is built
from (`src/` without `src/gen/`, `syntaxes/`, `media/`, the manifests, the
two `.proto` schemas), `pnpm build` writes that hash in `dist/source-hash`,
the vsix carries it, and the script compares it with the hash of the
installed copy: equal, nothing happens; different or none, build, package
and `code --install-extension --force`. Reload the window after an install.
The `version` of `package.json` is frozen at `0.0.0` and never bumped: the
hash is what tells two builds apart. `pnpm watch` plus F5 (Extension
Development Host) works for iterating without installing.

## Deliberate simplifications

- No settings and no persistence: the hub URL is a constant, the grouping of
  the log levels view, the display filter and the log store reset with the
  window.
- The display filter is keyed by (node, module) pair: a level set on a node
  or on a folder is written on every module below it, and a module that
  appears later starts at INFO like everything else.
- The search filters the rendered lines rather than the records, which is
  what makes it search the kind and the module name too. No regex, no case.
- The nodes view refreshes on the gateway's table (once a second), so the
  live/fading dot is that old at worst.
- The colors are a grammar over standard scopes, no theme and no semantic
  tokens: whatever theme is in use colors the lines, and none of the four
  scoped levels is guaranteed a color of its own.
- "Reset levels to INFO" has no title button: the gear already asks for a
  level, and INFO is one of the five it offers.

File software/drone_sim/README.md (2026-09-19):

# drone_sim

The desktop flight process: the flight core plus the sim composition of
platform services (`software/components/platform/src/sim/`), one
transport node on the shared discovery port. `main.cpp` parses the
arguments, builds `DroneSimApp`, runs it.

```sh
./software/build/desktop/drone_sim/drone_sim [--discovery-port N] [--node-id N] [--ota-dir DIR]
```

## Telemetry

The process exposes its measures on demand rather than pushing them: 76 of
them (the sensor frame, both estimators, the throw detector, the three
control loops, the mixer, the plant truth and the attitude error), listed in
`software/components/telemetry/README.md` and logged at boot by
`platform/telemetry`. `MIN_TELEMETRY_PERIOD_MS` is 2 ms here, the frame
period: the plant paces the loop at 500 Hz and a loopback datagram costs
nothing, so there is nothing faster to ask for.

It emits nothing unasked. The `Status` report, one message every 10 frames
(attitude, motors, phase, throw state and count, the two validity flags and
the plant's exact state), goes to the nodes that subscribed to it, and so
do the log lines and the telemetry samples; everything it answers
(descriptor pages, tuning acks and pages, updater replies) goes to the node
that asked. The process holds one `Messenger` over its transport, polled
from inside the sensor wait, and its handlers are the provider of each
concept (`status/`, `log/`, `telemetry/`, `tuning/`, `ota/`), the
`Discovery` that says who this process is, and the App's own `Commands`
handler (RC, reboot, scenario).

## No plant needed to start

The process runs its loop at 500 Hz from the moment it starts, plant or
not. Without a plant the frames come from the platform clock with no
sensors (`imu_valid` and `baro_valid` false in the Status report): the flight
core stays idle, arming is refused, motors are zero, and every handler
keeps being served (RC tracked, tuning answered, OTA against the emulated
flash, log levels). When a Godot plant appears the platform adopts it
(`sim/plant` INFO `plant <id> connected`), the frames switch to the plant's
simulated time and sensors, and the flight core is restarted on the new time
base; a throw scenario then runs as usual. When the plant goes silent for
500 ms it is dropped (`plant <id> lost`), the clock takes over and the
core is restarted again, idle. The application never knows whether a
plant is there: only the platform does.

The run hash covers plant frames only: frames without sensors are not part
of any run. Nothing publishes it on the wire; the tracker logs it as an
`flight/core` line when the run seals.

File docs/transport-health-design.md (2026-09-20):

# Transport health - design

Decided on 2026-09-19. The state of the transport layer of the whole
system, seen from every node, gathered by the hub and shown as a graph in
the editor: which nodes are on the wire, over which links, how many frames
each one receives and loses from each other, and a verdict that says
whether the transport is healthy and, when it is not, why.

This document is the closed specification of the work: the subagents that
implement it take no decision of their own. What is not written here is
asked, not guessed. The code is the reference once merged; where the code
had to depart from this document, section 9 says so.

## 1. Why

Every node's transport keeps a table of its peers with `received`, `lost`,
`duplicates`, `hops` and `lastSeenUs` per peer, and global send counters
(`sent`, `sentBytes`, `refused`, `dropped`, `relayed`). Every messenger
keeps its own (`undecodable`, `unhandled`, `requests`, `resent`,
`completed`, `failed`, `unmatchedAcks`). Today only the hub's table is
visible (`NodeTable` of `gateway.proto`), and only from the hub's point of
view.

A loss on the direction A to B is only seen by B. The hub's table shows
the losses towards the hub and never the losses towards the board (hub,
relay, UART), which are exactly the ones that make requests fail. The
feature is therefore: every node reports its own view of the transport,
the hub gathers every view into the directed matrix (observer, peer), and
derives from it what a person needs to know.

## 2. Principles

- Nothing travels unasked. A node reports only to the nodes that
  subscribed, and the hub subscribes only while a websocket client asked
  for the reports (the transport page is open). With no client marked, the
  hub's own view is the whole picture, and it costs the wire nothing.
- Counters travel cumulative, never as rates: a lost report skews nothing,
  the hub computes the deltas.
- The hub is provider and consumer of the concept: it reports to another
  gateway that subscribes, and it feeds its own consumer through a local
  path since a messenger cannot send to its own node.
- The GDScript plant and the Dart phone do not report in this version.
  They still appear as peers in everyone else's reports, with only their
  inbound direction known, and the page draws them as such.
- No new unit test is written; the existing tests are adapted where an API
  they exercise changes. Candidates for the testing design are listed in
  section 8.
- Every rule of `CLAUDE.md` holds: English, ASCII, `mark4` namespace, no
  heap in the components, Doxygen, Conventional Commits, the log library
  for every diagnostic line.

## 3. Transport additions (`software/components/transport/`)

### 3.1 `AbsLink` (`transport/link.hpp`)

```cpp
/// What medium a link is: what a report says of it, and what a page draws.
enum class LinkKind : std::uint8_t
{
    UART = 1, ///< a point-to-point serial line behind the serial framing
    UDP = 2,  ///< an IPv4 LAN, one shared discovery port and one data socket
};

/// @return what medium this link is
[[nodiscard]] virtual LinkKind kind() const = 0;

/// @return frames the medium could not deliver whole, cumulative: a CRC
///         failure or an impossible length on a serial line, a datagram
///         larger than the caller's buffer on UDP
[[nodiscard]] virtual std::uint32_t rxErrors() const = 0;
```

`UartLink::kind()` returns `UART`; `UdpLink::kind()` returns `UDP`.

`UartLink::rxErrors()` is the parser's count plus the frames dropped for
being larger than the caller's capacity in `receive()`. `SerialFrameParser`
gains a `std::uint32_t m_errors` counter and an accessor `errors()`,
incremented on a CRC mismatch and on an impossible announced length (0 or
greater than `SERIAL_MAX_PAYLOAD`), the two places where the parser goes
back to `SYNC0` without returning a frame. A stray byte while hunting for
the sync pair is not an error: that is the normal resynchronization.

`UdpLink::rxErrors()` counts the oversized datagrams `ReadOne()` skips
(`received > capacity`); the counter is a member of the link and `ReadOne`
becomes a non-static member (or takes the counter by reference; the
implementer picks the smaller change).

The test fake `software/tests/unit/recording_link.hpp` (`RecordingLink`)
implements both: `kind()` returns `LinkKind::UDP`, `rxErrors()` returns 0.
Nothing else implements `AbsLink` outside `transport/`.

### 3.2 `Transport` (`transport/transport.hpp`)

Per-link counters, indexed like `m_links`:

```cpp
/// What crossed one link, in both directions, cumulative.
struct LinkStats
{
    std::uint32_t framesIn = 0U;  ///< frames the link handed over, header decoded or not
    std::uint32_t bytesIn = 0U;   ///< their bytes, header included
    std::uint32_t framesOut = 0U; ///< frames the link took: this node's sends,
                                  ///< its keepalives and what it relayed
    std::uint32_t bytesOut = 0U;  ///< their bytes, header included
    std::uint32_t refused = 0U;   ///< frames the link would not take (a full UART ring)
};

[[nodiscard]] std::size_t linkCount() const;
[[nodiscard]] const AbsLink &link(std::size_t index) const;      // 0 <= index < linkCount()
[[nodiscard]] const LinkStats &linkStats(std::size_t index) const;
```

Rules:

- `poll()` counts every frame a link's `receive()` returns in `framesIn`
  and `bytesIn` of that link, before `onFrame()` looks at it.
- Every `send()` / `broadcast()` call on a link, from `send()`,
  `sendKeepalive()` and `relay()`, counts in `framesOut` and `bytesOut`
  (the whole frame size) when the link returned true, in `refused` when it
  returned false. The existing global counters keep their meaning exactly
  (`sent()` and `refused()` describe this node's own sends and keepalives,
  `relayed()` counts the forwards whether the link took them or not).

Two churn counters on the transport:

```cpp
/// @return peers forgotten for silence (NODE_EXPIRY_US), cumulative
[[nodiscard]] std::uint32_t expired() const;
/// @return peers seen restarting (another boot id), cumulative
[[nodiscard]] std::uint32_t restarted() const;
```

`expire()` increments the first per node forgotten; `onBootId()` increments
the second when it fires `notifyDown` then `notifyUp`.

The GDScript and Dart ports are not touched: they neither report nor need
the new counters.

`transport/README.md` documents the new counters (API section, Links
section) and gains a section on the provider and the consumer (section 4
below).

## 4. Wire (`software/components/protocol/mark4.proto`)

Three bodies in the `Envelope` oneof, numbered after the last one in use:

```proto
TransportSubscribe transport_subscribe = 54;
TransportSubscription transport_subscription = 55;
TransportReport transport_report = 56;
```

Messages, placed after the tuning family with the same comment style as
the other concepts:

```proto
// The transport concept: what every node's transport and messenger count.
// Request, answered by the subscription as held (TransportSubscription).
message TransportSubscribe {
  bool enabled = 1;
}

// The subscription as the provider holds it.
message TransportSubscription {
  bool enabled = 1;
}

enum LinkKind {
  LINK_KIND_UNSPECIFIED = 0;
  LINK_UART = 1;  // a point-to-point serial line
  LINK_UDP = 2;   // an IPv4 LAN
}

// One physical link of the reporting node, cumulative counters.
message TransportLink {
  LinkKind kind = 1;
  uint32 frames_in = 2;
  uint32 bytes_in = 3;
  uint32 frames_out = 4;
  uint32 bytes_out = 5;
  uint32 refused = 6;    // frames the medium would not take (a full UART ring)
  uint32 rx_errors = 7;  // frames the medium could not deliver whole (CRC, length, oversize)
}

// One peer as the reporting node's transport holds it.
message TransportPeer {
  uint32 id = 1;
  uint32 link = 2;        // index into TransportReport.links
  uint32 hops = 3;        // relays the last frame from it crossed
  uint32 received = 4;
  uint32 lost = 5;
  uint32 duplicates = 6;
  uint32 age_ms = 7;      // since the last frame from it
}

// Stream: one node's view of the transport, every second, to the nodes
// that subscribed. Cumulative counters, so a lost report skews nothing.
// The peer table travels by pages of at most 4 (peer_cursor, peer_total),
// every page carrying the counters again; a consumer takes the counters
// from any page and replaces the peer slice the page names.
message TransportReport {
  // this node's transport
  uint32 sent = 1;            // frames this node handed to a link: its sends and keepalives
  uint32 sent_bytes = 2;      // their payload bytes
  uint32 refused = 3;         // sends that reached no link
  uint32 dropped = 4;         // frames dropped: too short, table full, nobody to relay to
  uint32 relayed = 5;         // frames forwarded onto another link
  uint32 expired = 6;         // peers forgotten for silence
  uint32 restarted = 7;       // peers seen restarting (another boot id)
  // this node's messenger
  uint32 undecodable = 8;     // payloads that were no Envelope
  uint32 unhandled = 9;       // messages nobody claimed
  uint32 requests = 10;       // requests started
  uint32 resent = 11;         // requests sent again
  uint32 completed = 12;      // requests acknowledged
  uint32 failed = 13;         // requests given up on
  uint32 unmatched_acks = 14; // acknowledgements matching no pending request
  repeated TransportLink links = 15;  // at most 4, in declaration order
  uint32 peer_cursor = 16;    // index of peers[0] in the node table
  uint32 peer_total = 17;     // peers in the whole table
  repeated TransportPeer peers = 18;  // at most 4 per page
}
```

`mark4.options`:

```
mark4.TransportReport.links         max_count:4
mark4.TransportReport.peers         max_count:4
```

Worst case of one page encoded: about 450 bytes, under `MAX_PAYLOAD` (512),
and the struct stays under `MAX_ENVELOPE_STRUCT_SIZE` (400); both are
checked by the build (`static_assert` in `protocol/envelope.hpp`, the
nanopb `_size` constant). If either limit is hit, the implementer stops
and reports rather than lowering a bound.

No `reserved` statement (the godobuf parser cannot read it). The wire hash
changes: every node rebuilds, which is the normal course of a schema
change. The GDScript and Dart codecs regenerate from the schema at build
time and their messengers acknowledge and drop the tags they do not claim.

`protocol/README.md` lists the three messages with the other concepts.

## 5. The concept in `transport/`: provider and consumer

Same directory as the leaf, on the model of `log/` (the leaf `log`, then
`log_provider` and `log_consumer` next to it). Two header-only targets,
each header with its one-include source in `src/` (the rule of PR #33):

- `transport_provider`: `include/transport/provider.hpp`,
  `src/provider.cpp`; links `messaging` and `log` PUBLIC, `drone_warnings`
  and `drone_strict` PRIVATE.
- `transport_consumer`: `include/transport/consumer.hpp`,
  `src/consumer.cpp`; links `messaging`, `discovery` and `log` PUBLIC,
  `drone_warnings` and `drone_strict` PRIVATE.

Log module ids in `log/module_ids.hpp`:

```cpp
inline constexpr std::uint16_t LOG_MODULE_TRANSPORT_PROVIDER = 27U; ///< transport/provider
inline constexpr std::uint16_t LOG_MODULE_TRANSPORT_CONSUMER = 28U; ///< transport/consumer
```

### 5.1 `TransportProvider`

```cpp
class TransportProvider final : public AbsMessageHandler
{
  public:
    static constexpr std::array<pb_size_t, 1> TAGS = {mark4_Envelope_transport_subscribe_tag};
    static constexpr std::uint64_t REPORT_PERIOD_US = 1'000'000U;
    static constexpr std::size_t MAX_SUBSCRIBERS = 2U;
    static constexpr std::size_t PEERS_PER_PAGE = 4U;   // = the nanopb bound

    /// @param messenger the subscribes come from it, the reports leave by it,
    ///        and its counters are part of the report
    /// @param transport what is reported; must outlive the provider
    TransportProvider(Messenger &messenger, const Transport &transport);

    /// @brief Sends the report when due, to every subscriber: one page
    ///        per PEERS_PER_PAGE peers, all pages in the same call. With no
    ///        subscriber nothing is packed at all.
    /// @param nowUs current instant [us], from the caller's clock
    void tick(std::uint64_t nowUs);

    /// @brief Fills one page of the report, as tick() sends it. Public so a
    ///        node that consumes its own report (the gateway) can walk the
    ///        pages without the wire.
    /// @param cursor index of the first peer of the page
    /// @param nowUs current instant [us], for the ages
    /// @param[out] out the page
    /// @return peers written, 0 when cursor is past the table (the page
    ///         still carries the counters and peer_total)
    std::size_t fillPage(std::uint32_t cursor, std::uint64_t nowUs, mark4_TransportReport &out) const;

    bool onMessage(std::uint32_t src, const mark4_Envelope &envelope, std::uint64_t nowUs) override;
    void onNodeDown(std::uint32_t nodeId) override;

    [[nodiscard]] std::size_t subscribers() const;
    [[nodiscard]] std::uint32_t reportsSent() const;   // pages sent
};
```

Behaviour, copied from `StatusProvider` where it applies:

- `onMessage` on `transport_subscribe`: add or remove `src` in a
  `SubscriberTable<MAX_SUBSCRIBERS>`; a full table is a WARN of
  `transport/provider` and `applied = false`; answer with
  `TransportSubscription { enabled = applied }` sent as a `request()`.
- `onNodeDown`: remove the node, INFO line like the status provider's.
- `tick`: nothing with no subscriber. Otherwise when `nowUs -
  m_lastReportUs >= REPORT_PERIOD_US` (the first tick sends at once):
  `cursor = 0; do { fillPage(cursor, nowUs, page); send to every
  subscriber with Messenger::send(); cursor += page.peers_count; } while
  (cursor < page.peer_total);`. A stream: `send()`, never `request()`.
- `fillPage`: the transport counters and the messenger counters
  (`accessMessenger()` gives the messenger; every counter it exposes is a
  const accessor), `links` from `linkCount()` / `link(i).kind()` /
  `linkStats(i)` / `link(i).rxErrors()`, `peer_total = nodeCount()`,
  `peers` from `node(cursor + k)` for `k < PEERS_PER_PAGE`, `age_ms =
  (nowUs - min(nowUs, lastSeenUs)) / 1000`.

### 5.2 `TransportConsumer`

Non-template base over a storage span plus `TransportConsumer<N>`, exactly
the shape of `status/consumer.hpp` (read it first and copy its structure:
listener class with attach/detach, `Entry` table as a dense prefix, `open`,
`lookup`, `onNodeDown`, `onRequestFailed`, `Module()`).

```cpp
class AbsTransportConsumerListener
{
    /// @brief One node's report, pages merged: fired when the last page of
    ///        a report arrived.
    virtual void onReport(std::uint32_t nodeId, const TransportConsumerBase::Entry &entry, std::uint64_t nowUs) = 0;
    /// @brief A node went down: everything the consumer held of it is gone.
    virtual void onForgotten(std::uint32_t nodeId) = 0;
};

class TransportConsumerBase : public AbsMessageHandler, public AbsDirectoryListener
{
  public:
    static constexpr std::array<pb_size_t, 2> TAGS = {mark4_Envelope_transport_report_tag,
                                                      mark4_Envelope_transport_subscription_tag};
    /// Kinds that carry a TransportProvider in this version.
    static constexpr std::array<mark4_NodeKind, 4> KINDS = {FIRMWARE, DRONE_SIM, RELAY, GATEWAY};
    static constexpr std::size_t MAX_LISTENERS = 2U;
    /// Peers one report may hold once its pages are merged: a transport's table.
    static constexpr std::size_t MAX_PEERS = Transport::MAX_NODES;

    struct Entry
    {
        std::uint32_t id = 0U;
        bool local = false;                  ///< this node's own report, fed by accept(), never subscribed
        bool subscribed = false;             ///< the node took the subscribe
        std::uint32_t subscribeRequest = 0U; ///< subscribe (or unsubscribe) waiting for its answer, 0 none
        bool hasReport = false;              ///< a complete report arrived
        mark4_TransportReport last;          ///< counters and links of the last complete report; its peers field is unused
        std::array<mark4_TransportPeer, MAX_PEERS> peers{}; ///< the merged peer table of that report
        std::size_t peerCount = 0U;
        std::uint64_t receivedUs = 0U;       ///< instant the last complete report arrived [us]
        std::uint32_t reports = 0U;          ///< complete reports from this node
        // staging of the report being received
        std::array<mark4_TransportPeer, MAX_PEERS> staging{};
        std::size_t stagingCount = 0U;
        bool staging_valid = false;          ///< a page with cursor 0 opened the staging
    };

    TransportConsumerBase(Messenger &, DiscoveryDirectory &, std::span<Entry>);
    [[nodiscard]] bool init() const;

    /// @brief Asks every node open now and later for its reports, or stops
    ///        asking: one TransportSubscribe per remote entry, as a request.
    ///        Turning it off also forgets the reports held of the remote
    ///        entries (hasReport = false), so nothing stale is published;
    ///        the local entry keeps its own.
    void setWanted(bool wanted);
    [[nodiscard]] bool wanted() const;

    /// @brief Opens the entry of this node's own report, fed by accept()
    ///        and never subscribed to. Once, by the composition.
    /// @return false when the table is full
    bool openLocal(std::uint32_t id);

    /// @brief Takes one page of one node's report: the counters are copied,
    ///        the peer slice [peer_cursor, peer_cursor + n) replaces the
    ///        staging; when the page completes the table (cursor + n >=
    ///        peer_total, or peer_total == 0) the staging becomes the
    ///        report, hasReport is set, reports is counted and the
    ///        listeners hear onReport(). A page with cursor 0 always opens
    ///        a new staging; a page whose cursor is not where the staging
    ///        ended is dropped (a lost page: the next report starts over).
    void accept(std::uint32_t nodeId, const mark4_TransportReport &page, std::uint64_t nowUs);

    void onIdentity(const DirectoryEntry &) override;   // open on a KINDS kind with no wireMismatch; subscribe if wanted
    void onForgotten(std::uint32_t) override;           // nothing: presence does it
    bool onMessage(...) override;                       // report page -> accept(); subscription -> entry state
    void onNodeDown(std::uint32_t) override;            // drop the entry, tell the listeners
    void onRequestFailed(std::uint32_t, std::uint32_t) override;  // WARN like the status consumer

    [[nodiscard]] const Entry *find(std::uint32_t id) const;
    [[nodiscard]] std::size_t size() const;
    [[nodiscard]] const Entry &entry(std::size_t index) const;
};

template <std::size_t N> class TransportConsumer final : public TransportConsumerBase { ... };
```

The `TransportSubscription` answer sets `entry.subscribed = enabled` and
clears `subscribeRequest`. `setWanted(false)` sends `TransportSubscribe {
enabled = false }` to every subscribed remote entry. An `Entry` weighs
about 2.2 kB; `TransportConsumer<Transport::MAX_NODES>` on the hub is
about 70 kB, which is the hub's business.

### 5.3 Compositions

Every C++ node gets a provider, declared after its `LogProvider` and
ticked where its messenger is polled:

- `drone_sim` (`software/drone_sim/drone_sim_app.hpp` / `.cpp`):
  `mark4::TransportProvider m_transportProvider{m_messenger, m_transport};`
  ticked with `m_clock.nowUs()` in the run loop next to the updater's
  tick.
- firmware (`software/drone_firmware/firmware_app.hpp` / `.cpp`): member
  after the log provider, ticked in `pollTransport(nowUs)` after
  `m_messenger.poll(nowUs)`. It builds for the F405 as it stands (no heap,
  `drone_strict`).
- relay (`esp32-bridge/main/relay.cpp`): a member of `Relay` after
  `logProvider`, ticked in the loop after `messenger.poll()`;
  `esp32-bridge/main/CMakeLists.txt` adds
  `${DRONE_TRANSPORT}/src/provider.cpp` to the sources like
  `log/src/provider.cpp`. The relay's `STATS.debug` line stays.
- hub: section 6.

The pending request tables are untouched: the provider sends the answer to
a subscribe as one request, which the board's table of 4 affords.

## 6. The hub (`software/hub/`)

### 6.1 `gateway.proto`

```proto
// in the GatewayMessage oneof
TransportCommand transport_command = 55;
NodeTransport node_transport = 67;
TransportHealth transport_health = 68;
```

`Node` loses `received`, `lost` and `duplicates`: the three numbers become
`reserved 5, 6, 7;` with the comment "were the gateway's own receive
counters, which live in NodeTransport now; never reuse". `NodeTable` is
identity and presence only: id, address, port, `last_seen_ms_ago`,
`announce`.

```proto
// Client to gateway: this client wants the transport reports of every
// node. The gateway subscribes to the nodes while at least one client is
// marked, and unsubscribes when the last one clears or disconnects. Its own
// report needs no subscription and is always published.
message TransportCommand {
  bool subscribe = 1;
}

// Gateway to client: one node's view of the transport, the last report it
// sent (pages merged) plus what the gateway derives from it over a sliding
// window. Published on every complete report; the gateway's own every
// second. A client that connects gets every one held.
message NodeTransport {
  uint32 node = 1;
  TransportReport report = 2;       // counters and links as reported; peers is empty here, the edges carry them
  uint32 window_ms = 3;             // span of the rates below, 0 while one report only
  repeated TransportLinkRate links = 4;   // one per report.links entry
  repeated TransportEdge edges = 5;       // one per peer the node holds, 32 at most
  TransportWindow window = 6;       // this node's own counters over the window
}

// One link of a node over the window.
message TransportLinkRate {
  float frames_in_per_s = 1;
  float bytes_in_per_s = 2;
  float frames_out_per_s = 3;
  float bytes_out_per_s = 4;
  uint32 refused = 5;    // over the window
  uint32 rx_errors = 6;  // over the window
}

// One directed edge: what the reporting node (the observer) counts of one
// peer, cumulative as reported and as rates over the window.
message TransportEdge {
  uint32 peer = 1;
  uint32 link = 2;             // index into NodeTransport.report.links
  uint32 hops = 3;
  uint32 age_ms = 4;
  uint32 received = 5;
  uint32 lost = 6;
  uint32 duplicates = 7;
  float rx_per_s = 8;          // frames per second over the window
  float loss = 9;              // lost / (received + lost) over the window, 0..1
  float duplicates_per_s = 10;
}

// A node's own counters over the window: what happened lately rather than
// since boot.
message TransportWindow {
  uint32 sent = 1;
  uint32 refused = 2;
  uint32 dropped = 3;
  uint32 relayed = 4;
  uint32 expired = 5;
  uint32 restarted = 6;
  uint32 requests = 7;
  uint32 resent = 8;
  uint32 failed = 9;
  uint32 undecodable = 10;
  uint32 unhandled = 11;
}

enum TransportVerdict {
  VERDICT_UNKNOWN = 0;   // nothing to judge yet
  VERDICT_OK = 1;
  VERDICT_DEGRADED = 2;
  VERDICT_BAD = 3;
}

// One node as the gateway judges it from every view it holds.
message TransportNodeHealth {
  uint32 node = 1;
  TransportVerdict verdict = 2;
  bool reporting = 3;        // a complete report of its own is held (the gateway itself always)
  float worst_in_loss = 4;   // worst loss over the edges this node observes
  float worst_out_loss = 5;  // worst loss over the edges other nodes observe of it
  bool fading = 6;           // some observer heard it more than 1.5 s ago
  bool asymmetric = 7;       // a reporting node lists it and it does not list that node back
  bool link_refused = 8;     // one of its links refused frames in the window
  bool link_rx_errors = 9;   // one of its links had receive errors in the window
  bool requests_failed = 10; // it gave up on requests in the window
  bool churn = 11;           // it expired or saw restart a peer in the window
}

// Gateway to client: the verdict on the whole transport, published every
// second and to a client that connects. With no client marked it is built
// from the gateway's own view alone, which nodes_reporting says.
message TransportHealth {
  TransportVerdict verdict = 1;
  uint32 nodes_known = 2;      // the node table, the gateway included
  uint32 nodes_reporting = 3;
  uint32 worst_observer = 4;   // the edge with the worst loss, 0 when none
  uint32 worst_peer = 5;
  float worst_loss = 6;
  float frames_per_s = 7;      // sum of rx_per_s over every edge held
  repeated TransportNodeHealth nodes = 8;   // one per node of the table, 33 at most
}
```

`gateway.options`:

```
mark4.NodeTransport.links           max_count:4
mark4.NodeTransport.edges           max_count:32
mark4.TransportHealth.nodes         max_count:33
```

### 6.2 `TransportGateway` (`hub/gateway_transport.hpp` / `.cpp`)

An `AbsTransportConsumerListener` like the other gateways, holding the
publisher, the consumer, the provider (for its own pages) and the
transport's node id. Hub code: `std::map`, `std::set`, `std::deque` are
fine here.

- **Marks**: `apply(const mark4_TransportCommand &, clientId, errorOut)`
  inserts or erases the client in a `std::set<std::string>`;
  `onClientClosed(clientId)` erases it; whenever the set goes from empty
  to non-empty or back, `m_consumer.setWanted(!empty)`. An `Ack` answers
  the command like every other.
- **Own report**: `tick(nowUs)` once per second (the gateway's
  `STATUS_PERIOD_MS` cadence, driven from `housekeeping()`): walks
  `m_provider.fillPage()` pages and feeds them to
  `m_consumer.accept(selfId, page, nowUs)`; the consumer's `openLocal(selfId)`
  is called once by the gateway's constructor. Then `publishHealth()`.
- **Window**: per node, a `std::deque<Sample>` of at most `WINDOW = 10`
  samples, one per `onReport()` (the counters, the links, the peers, the
  instant). Rates: newest against oldest, `window_ms` = their span, 0 with
  a single sample (rates 0, window counters 0). `onForgotten()` drops the
  deque; `setWanted(false)` (the last client left) also drops every remote
  deque, so a client that connects later sees only the gateway's own.
- **`onReport()`**: push the sample, build `NodeTransport` (section 6.3),
  broadcast.
- **`onClientConnected()`**: every `NodeTransport` held (nodes with a
  report), then the last `TransportHealth`, to that client alone.
- **`publishHealth()`**: builds and broadcasts `TransportHealth` (section
  6.4).

### 6.3 Derivation of `NodeTransport`

For a node with samples `newest` and `oldest` (the same sample when only
one), `span = newest.t - oldest.t` in seconds:

- `report`: `newest.report` with `peers_count = 0`.
- `links[i]`: `frames_in_per_s = (newest.links[i].frames_in -
  oldest.links[i].frames_in) / span` and the three others alike; `refused`
  and `rx_errors` as deltas. All zero when `span == 0`. A link index the
  oldest sample does not have is treated as zeros.
- `edges`: one per peer of `newest`; the cumulative fields as reported;
  the deltas against the same peer id in `oldest` (a peer absent from
  `oldest` counts as zeros): `rx_per_s = d_received / span`, `loss =
  d_lost / (d_received + d_lost)` (0 when the denominator is 0),
  `duplicates_per_s = d_duplicates / span`.
- `window`: the deltas of the node counters.

### 6.4 Derivation of `TransportHealth`

Thresholds, constants of `gateway_transport.hpp`:

| constant | value | meaning |
|---|---|---|
| `LOSS_DEGRADED` | 0.01 | edge loss above this is DEGRADED |
| `LOSS_BAD` | 0.10 | edge loss above this is BAD |
| `FADING_MS` | 1500 | an edge older than this is fading |

Per node of the node table (the gateway first, then the transport table
like `nodesMessage()`):

- `reporting`: the consumer holds a complete report of it.
- edges in: the node's own edges (when reporting); `worst_in_loss` = max
  loss over them.
- edges out: every edge of every reporting node whose `peer` is this node;
  `worst_out_loss` = max loss over them; `fading` = any of them with
  `age_ms > FADING_MS`.
- `asymmetric`: this node is reporting, some other reporting node A lists
  it as a peer, and this node's edges do not list A.
- `link_refused`, `link_rx_errors`: any link of its `NodeTransport` with a
  non-zero window delta.
- `requests_failed`: `window.failed > 0`.
- `churn`: `window.expired + window.restarted > 0`.
- verdict: start OK; `max(worst_in_loss, worst_out_loss) > LOSS_DEGRADED`
  or `fading` or `link_refused` or `link_rx_errors` or `churn` makes it
  DEGRADED; `> LOSS_BAD` or `asymmetric` or `requests_failed` makes it
  BAD. A node that is not reporting and that no edge observes (no report
  anywhere lists it) is UNKNOWN.

System: `verdict` = the worst node verdict (UNKNOWN when the table holds
only the gateway); `worst_observer` / `worst_peer` / `worst_loss` = the
edge with the highest loss over every edge held (0 / 0 / 0 when none);
`frames_per_s` = the sum of `rx_per_s`; `nodes_known` = the table size,
`nodes_reporting` = the count of reporting nodes.

The derivation is written as free functions in `hub/transport_health.hpp`
(pure: inputs are the samples, output the messages), so the gateway is
wiring and the arithmetic reads alone.

### 6.5 `HubApp` wiring

- Members, in declaration order after the existing consumers: `TransportConsumer<Transport::MAX_NODES> m_transport{m_messenger, m_directory};`
  (name it `m_transportViews` to avoid clashing with `m_transport` the
  Transport), then after `m_logProvider`: `TransportProvider
  m_transportProvider{m_messenger, m_transport};`, then with the other
  gateways: `TransportGateway m_transportGateway{*this, m_transportViews, m_transportProvider, m_transport.nodeId()};`.
- `applyClientMessage`: `transport_command_tag` routes to
  `m_transportGateway.apply(...)`.
- `snapshot()`: `m_transportGateway.onClientConnected(clientId)` with the
  others.
- `housekeeping()`: `m_transportGateway.onClientClosed()` in the drainClosed
  loop; `m_transportGateway.tick(nowUs)` inside the once-per-second block,
  before `statusMessage()`.
- `gateway_codec.cpp` `fillNode()` stops writing the three removed fields.
- `GatewayStatus` is unchanged.

`hub/README.md` gains the concept (consumer, gateway, marks, own report,
the two messages) and `protocol/README.md` the gateway messages. The
`CLAUDE.md` architecture paragraphs (the gateway message list under
`protocol/`, the `transport/` paragraph) name the new messages and the
provider/consumer in one sentence each.

## 7. Clients
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

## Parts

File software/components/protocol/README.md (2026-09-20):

# protocol

The wire of the project: two schemas and the codecs the build generates
from them. `mark4.proto` is THE wire: every datagram and every serial frame
between the flight processes, the board, the plant and the ground tools
carries exactly one `Envelope`, a `oneof` over every message of the system
(the status report and its subscription, the telemetry family, the lockstep
sensor and actuator frames, RC, the identity pair, the log line, the module
table and the level move, scenario, tuning, updater, and the `RequestAck`
of the messenger). `gateway.proto` (imports it) is
the contract between the hub and its websocket clients: `GatewayMessage`,
a `oneof` over the `NodeTable`, one message per node and per concept (its
log modules and its lines, its last `Status`, its telemetry descriptors,
configuration and samples, its tuning table and results, its view of the
wire as `NodeTransport`), the commands a client sends (telemetry, log,
tuning, pilot input, node, transport, plus the `OtaCommand` of the updater
and the `ProfileCommand` of the tuning profiles), the `GatewayStatus`, the
`TransportHealth`, the `OtaState`, the `ProfileList` / `Profile`, and
`Ack`. No encoded `Envelope` crosses it in either direction:
the hub decodes everything it hears and publishes typed messages, and a
client sends typed commands. It never crosses the LAN. Its bodies share one
nanopb struct, so anything per-node and unbounded gets a message of its own
rather than a field in `Node`. Nothing generated is committed.

| Consumer | Generator | Output | When |
|---|---|---|---|
| every C/C++ target, desktop and STM32 | nanopb (FetchContent, `nanopb-0.4.9.2`, `PB_NO_MALLOC`, `PB_BUFFER_ONLY`, `PB_NO_ERRMSG` on the board) | `software/build/<preset>/gen/nanopb/mark4.pb.{c,h}` | the `nanopb` target, on every build |
| the hub (gateway.proto, desktop only) | nanopb, `gateway.options` | `software/build/desktop/gen/nanopb/gateway.pb.{c,h}` | the `nanopb_gateway` target of the desktop preset |
| the web pages (both schemas) | `protoc-gen-es` (`@bufbuild/protoc-gen-es`, npm) run by the `protoc` of `grpcio-tools` | `software/hub/pages/src/gen/{mark4,gateway}_pb.ts` (gitignored) | `pnpm gen`, run by every pnpm script of `software/hub/pages` |
| the Godot plant | godobuf, the addon committed in `sim-godot/addons/godobuf/` (pinned commit, BSD-3) run by a headless Godot through `scripts/gen_godobuf.py` | `sim-godot/scripts/gen/mark4.gd` and `wire_hash.gd` (gitignored) | target `proto_gd` of the desktop preset, when `godot` is on the PATH |

`mark4.options` bounds every field for nanopb (string sizes, fixed-count
float vectors, the 240-byte chunk, two OTA slots) so the structs hold their
storage inline, and gives every enum a fixed 32-bit underlying type so an
unknown value from a newer peer is a plain integer to compare, never an
out-of-range enum load. The generator needs the python packages `protobuf`
and `grpcio-tools` (the devcontainer image ships them); the configure step
says so when they are missing.

## What the C++ side gets

- `protocol/envelope.hpp`: `mark4.pb.h` plus `encodeEnvelope()` /
  `decodeEnvelope()`, buffer in, buffer out, no allocation, and
  `MAX_ENVELOPE_SIZE` (437 bytes today: a full `TelemetryData` batch of 32
  values, ahead of the 390-byte telemetry configuration and the 255-byte
  OTA chunk). Static asserts
  keep `sizeof(mark4_Envelope)` under 400 bytes, and the transport and
  serial framing check that every envelope fits their payloads. It is the
  one header the schema enters C++ through: it re-exports `mark4.pb.h`,
  `pb.h` and `protocol/wire_hash.hpp` (IWYU pragmas, honoured by clangd),
  so a file that uses a `mark4_*` type or `WIRE_HASH` includes it and
  never the generated headers directly.
- `protocol/wire_hash.hpp`: `WIRE_HASH`, the first 8 hex characters of the
  SHA-256 of `mark4.proto`, computed by CMake at configure time and
  regenerated on every edit of the schema. Every `Announce` carries it; the
  hub publishes its own in `GatewayStatus.wire_hash` and every node's last
  `Announce` in the `NodeTable`, the console shell compares the two and
  paints a mismatching chip red. `gateway.proto` is not part of the hash:
  the pages are generated from the same tree as the hub. The packaging
  script stamps it into the `.ota` manifest (`wireHash`) and the hub
  refuses a bundle built on another schema. The Godot plant reads its own
  from `wire_hash.gd`.
- `protocol/ota_image.hpp`: what is not wire but still crosses processes:
  the on-flash `OtaImageHeader`, the slot and chip identities in their
  flash encoding (`OTA_SLOT_*`, `OTA_MCU_*`, EMPTY is 0xFF on flash and 0
  on the wire, `otaSlotStateToWire()` maps), the chunk size and window.
Enum values are C-scoped inside the package, so two enums never share a
value name: `PHASE_*`, `THROW_*`, `RC_*`, `OTA_OK`, `OTA_OP_*` carry the
prefix the clash forced, the rest stay short. The flight core's own enums
(FlightPhase, ThrowState, PilotMode, TuningStatus) are pinned to the wire
value by value in `status/status_packer.hpp` and `tuning/provider.hpp`, and
`TelemetryUnit` is pinned to the leaf library's own enum in
`telemetry/provider.hpp`; flight-core never includes this library.

## Requests and answers

Every message is a unicast: nothing but the transport's own keepalive is
broadcast. A message that has to arrive carries a non-zero `request_id`
(field 100 of the `Envelope`, outside the oneof) and the receiving
messenger answers a `RequestAck` with that id on arrival, before it is
dispatched and whether or not any handler claims the body. The sender
resends until it comes back, then gives up
(`software/components/messaging/README.md`). An acknowledgement says
"arrived" and nothing about what was done, so an answer that matters is a
request of its own, correlated by its content and never by the id it
answers. Stream data (`Status`, `TelemetryData`, `Log`, `Rc`) carries no
id: a sample is only worth its own instant, and the subscription is what
guarantees the stream as a whole.

A request and its answer are two bodies, never one, because a node that is
the provider of a concept and a consumer of the same concept (the hub, for
its own log lines) holds one handler per body tag: the provider claims the
request tags and the consumer the state tags, and the two never meet.

## Where the messages travel

- `Status`, `TuningAck`, `TuningInfos`, the `Ota*` answers: flight process
  to ground, as unicasts to the node that asked or subscribed (drone_sim,
  and the board through the ESP32 relay). `Status`
  is the small fixed report of what the drone is doing, decimated to 50 Hz
  and emitted to whoever holds a `StatusSubscribe`: attitude, motors,
  phase, throw state and count, the two
  validity flags, whether the RC uplink is heard (`rc_link_ok`, the pilot's
  device reads it as "the drone hears me"), and the plant's exact state in
  `Status.truth` when the sender has one. `Status.imu_valid` / `baro_valid` repeat the validity
  flags of the frame that was stepped (a fresh measurement acquired for
  that frame, see `software/components/platform/README.md`);
  `PHASE_FAULT` is the flight core's latched motors-off state after the IMU
  was lost with the motors running.
- `IdentityRequest` and `Announce`, the identity pair: the request is
  unicast to one node, empty, and the node's `Announce` (kind, name, mcu,
  build identity, wire hash) is the unicast answer back to the requester,
  a request of its own so the asker acknowledges it.
  `drone_sim`, the firmware, the relay, the hub, the plant and the phone
  answer (`software/components/discovery/`); the hub, the plant and the
  phone ask. Presence on the wire
  stays the transport's keepalive, which carries the sender's boot id and
  no identity: nothing sends an `Announce` unsolicited.
- The telemetry family, all unicast:
  `TelemetryListRequest { cursor }` (ground to node) is answered by one
  `TelemetryDescriptors` page back to the requester;
  `TelemetrySubscribe { enabled }` takes the sample stream or stops it and
  is answered by a `TelemetrySubscription`; `TelemetryConfigure { ids,
  period_ms }` replaces the enabled set and the period wholesale, one
  configuration per node and never one per consumer, and is answered by
  the `TelemetryConfig` in effect, sent to the node that asked and to every
  other subscriber; `TelemetryData` carries one sampling instant of
  up to 32 values, split into several messages of the same timestamp when
  more are enabled. A measure is named by a stable path and routed by the
  id of the node's frozen table: see
  `software/components/telemetry/README.md`.
- The log family, all unicast: `Log` (one line, module by id) goes to the
  nodes that sent a `LogSubscribe { enabled }`, answered by a
  `LogSubscription`; `LogModulesRequest { cursor }` is answered by one
  `LogModules` page of the node's module table; `LogSetLevel { module_id,
  level }` moves one threshold and is answered by that module's
  `LogModuleInfo`, sent to the requester and to every other subscriber of
  the line stream. Every node speaks them, the hub included (its own lines
  leave from its node id). See `software/components/log/README.md`.
- `Rc`, `Reboot`, `SimScenario`, `TuningSet`, `TuningGet`,
  `TuningListRequest`, the `Ota*`
  requests: ground to flight process, as transport unicasts or serial
  frames. `Rc` is the pilot state as a stream (kill, arm, mode, throttle
  and the three sticks in the pilot's convention: positive is right,
  forward, clockwise), repeated at 20 Hz by a web page and 50 Hz by a
  gamepad path; the flight process treats 200 ms of silence as a kill
  (`platform_common/rc_tracker.hpp`) and reports whether it hears a pilot
  in `Status.rc_link_ok`. The sticks are raw positions: deadband, ranges
  and the mapping onto the body frame are the flight core's, tunable like
  a gain (`stick_*` in the tuning table).
- The transport family, all unicast: `TransportSubscribe { enabled }`
  takes a node's report stream or stops it and is answered by a
  `TransportSubscription`; `TransportReport` is one node's view of the
  wire, sent once a second to whoever subscribed. It carries that node's
  transport and messenger counters, one `TransportLink` per declared link
  (the medium as a `LinkKind`, the frames and bytes each way, what the
  medium refused and what it could not deliver whole) and its peer table
  as `TransportPeer` entries, by pages of four named by `peer_cursor` and
  `peer_total`. Every number is cumulative, so a lost report skews nothing
  and the reader takes the differences. Every C++ node answers
  (`software/components/transport/README.md`).
- `SimSensor` (truth included) and `SimActuator`: the lockstep exchange
  between a flight process and its plant, transport unicasts between the
  two node ids; `SimScenario` is forwarded to the plant the same way as
  its own envelope, once per scenario, and the plant plays it once per
  change of `sequence`.

The serial framing (`transport/serial_framing.hpp`) carries one envelope
per frame behind a two-byte length, 512 bytes at most like the transport's
`MAX_PAYLOAD`. The transport's keepalive is not an envelope at all: 11
bytes of header, flagged in the `flags:hops` byte, plus a 4-byte boot id
(`software/components/transport/README.md`).

## Changing the schema

A field number a message stops using is named in a comment and never
reused; `reserved` is not written, because the godobuf generator of the
Godot plant parses no such statement and would fail on the schema.

Edit `mark4.proto` (and `mark4.options` when a bound moves), rebuild: the
codecs regenerate, the wire hash changes, and every node built before
shows up as a wire mismatch on the pages instead of a silent bench. A board
running the previous schema still has to be reflashed once over SWD (or
updated by a hub built on the previous schema): see `docs/ota-design.md`.
The C++ unit tests round-trip every message
(`software/tests/unit/test_protocol_envelope.cpp`) and one test spawns a
headless Godot to exchange envelopes with the generated GDScript codec
through the two transports (`test_plant_link.cpp`, skipped without a godot
binary).

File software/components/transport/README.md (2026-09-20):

# transport

The interface manager between the processes and boards of the project. An
application declares its physical links (one per medium: a UDP socket pair,
a UART), then calls `send(node, payload)`; the transport remembers on which
link and at which address every node was last heard and emits there. The
payload is opaque: today it is one `Envelope` of `protocol/mark4.proto`,
and the transport does not link `protocol/` (it depends on `drone_warnings`
alone). The core and
the UART link build for every preset, the F405 included, with no heap and
fixed-size tables; the UDP link needs BSD sockets (desktop, and lwIP on the
ESP32).

Adopted by every node: `drone_sim` and the `hub` over UDP, the Godot plant
(a GDScript port, see below),
the board over its UART (the firmware is a node
with one `UartLink` on USART1), and the ESP32 riding the drone
(`esp32-bridge/`), which is a relay: a node with a `UartLink` to the board
and a `UdpLink` on the WiFi LAN. The hub holds one `UdpLink`, so it relays
nothing: the board reaches it as one more node of the LAN, at the relay's
address. The mobile app (`software/mobile`, kind
`PHONE`) compiles no native code: `lib/back/transport/` is a Dart port of
this directory, rule for rule and constant for constant.

## Frame

Every frame opens with an 11-byte little-endian header (`transport/frame.hpp`):

| field | type | meaning |
|---|---|---|
| `src` | u32 | node that produced the payload |
| `dst` | u32 | node it is for, `0` = every node (`BROADCAST_NODE`) |
| `seq` | u16 | counter of one stream, wraps: a stream is the frames from this sender to this destination, and the broadcast is a stream of its own |
| `flags:hops` | u8 | low nibble (`FRAME_HOPS_MASK`): relays crossed so far; a sender writes 0, a relay adds one and drops a frame already at `MAX_HOPS` = 4. High nibble: flags, bit 7 (`FRAME_FLAG_KEEPALIVE`) marking the transport's own keepalive, the others written 0 and ignored on read |

The payload follows, at most `MAX_PAYLOAD` = 512 bytes; a frame whose
header carries the keepalive flag is the transport's own (see Presence) and
is never delivered whatever it carries, and an application `send()` of an
empty payload is refused. A frame without the flag and without a payload is
nobody's message: it is learnt from like any other frame and delivered
nowhere. That is the compatibility rule with a node built before the flag
existed, whose keepalive is the header alone: it is still heard, its boot id
is simply unknown. A medium that keeps
datagram boundaries (UDP) adds nothing; the UART link wraps the frame in
the serial framing (`transport/serial_framing.hpp`: `A5 5A len_lo len_hi
payload crc16`, CRC-16/CCITT-FALSE over the two length bytes and the
payload), whose payload is capped at `SERIAL_MAX_PAYLOAD` = 512 bytes like
`MAX_PAYLOAD`, so a whole envelope fits behind the header.

## Node ids

Transport-level `uint32_t`, self-assigned at start, never configured, never
0. A desktop process draws one from `/dev/urandom` (`randomNodeId()`);
`drone_sim --node-id N` pins one so a launcher knows which node is
which process. An embedded target folds its MCU UID or MAC through
`hashNodeId(bytes, size)` (FNV-1a): the board hashes its MCU unique id,
the ESP32 relay its WiFi MAC.

## API (`transport/transport.hpp`)

```cpp
Transport transport(nodeId, bootId);   // value member of the App
transport.nodeId(); transport.bootId(); // who it is, and which run of it
transport.addLink(udpLink);            // up to MAX_LINKS = 4, AbsLink&
transport.init();                      // false without a node id or a link
transport.send(dst, payload, size);    // dst 0 = broadcast on every link, 1..MAX_PAYLOAD bytes
transport.poll(nowUs, deliver, context); // drain, learn, deliver, relay, expire, keepalive
transport.isAlive(id); transport.findNode(id); transport.nodeCount(); transport.node(i);
transport.dropped(); transport.relayed();
transport.sent(); transport.sentBytes(); transport.refused(); // this node's own sends
transport.expired(); transport.restarted();                   // churn in the node table
transport.linkCount(); transport.link(i); transport.linkStats(i); // one link, both directions

class Presence final : public AbsPresenceListener // up to MAX_LISTENERS = 4
{
    using AbsPresenceListener::AbsPresenceListener; // attaches to the transport
    void onNodeUp(const Transport::Node &node) override;
    void onNodeDown(const Transport::Node &node) override;
};
Presence presence{transport};          // a member declared after the transport
```

The send-side counters describe this node's own `send()` calls and its
keepalives, and nothing else (a relayed frame is somebody else's send:
`relayed()` is for those). `sent()` counts the frames that reached every
link they were meant for and `sentBytes()` their payloads (a keepalive
adds one frame and no byte); `refused()` counts the rest: an empty
payload or one longer than `MAX_PAYLOAD`, no link declared, an unknown
destination, or a medium that would not take the frame (a full UART
ring). They are what a
composition reports as its own output health, which is why they live here
rather than in a wrapper around `send()`.

Next to them, one `LinkStats` per declared link, indexed like the links
and cumulative: `framesIn` / `bytesIn` (every frame a link handed over,
whether or not its header decoded), `framesOut` / `bytesOut` (every frame
a link took, this node's sends, its keepalives and what it relayed) and
`refused` (the frames the medium would not take). Whole frames, header
included, where the global counters describe payloads: the two answer
different questions, "what does this node say" and "what crosses this
wire". Two more counters describe the churn of the node table: `expired()`
counts the peers forgotten for silence and `restarted()` the peers seen
coming back with another boot id.

`poll()` is the only place anything happens, and `nowUs` comes from the
caller: the transport never reads a clock. Every frame received, whatever
its payload, refreshes the node table (`nodeId -> link, address,
lastSeenUs, txSeq, unicastSeq, unicastHeard, broadcastSeq, broadcastHeard,
received, lost, duplicates, hops, boot`, `MAX_NODES` = 32);
a payload addressed to this node or to everyone is handed to `deliver`,
and a keepalive, or a frame carrying no payload, is not. A frame whose `src` is
this node (its own broadcast coming back on a shared medium) is ignored.

A broadcast leaves on every declared link; a unicast leaves on the link
its destination was last heard on, and is refused while the destination is
unknown.

Sequence accounting per stream, not per sender. A sender keeps one counter
per node it knows (`Node::txSeq`, 0 when the entry is created and again
when a reincarnation rebuilds it) plus one for the broadcast; a receiver
keeps one sequence per peer and per stream (`unicastSeq` for what a peer
addresses to this node, `broadcastSeq` for what it addresses to everyone,
each one meaningless until its `unicastHeard` / `broadcastHeard` flag is
set by the first frame of that stream, whose sequence is taken as it is).
Inside one stream: an exact repeat of the last sequence is a duplicate and
is dropped; a forward gap below `RESYNC_THRESHOLD` (1024) is counted as
lost frames; a larger jump is a restarted sender and counts as nothing.
`received`, `lost` and `duplicates` are the two streams together. A frame
addressed to a third node says its sender is there and nothing more: it
refreshes the link, the address, `lastSeenUs` and `hops` and is numbered in
neither stream, because this node hears only the part of that stream its
own relaying carries. One counter for everything a sender emits would make
every unicast it sends elsewhere read as a lost frame for everybody else.
The hub publishes these counters per observed edge (`TransportEdge` of
`gateway.proto`), an edge being one pair (observer, peer).

## Presence

Presence is the keepalive, a frame flagged `FRAME_FLAG_KEEPALIVE` in its
header and carrying `KEEPALIVE_PAYLOAD_SIZE` = 4 bytes, the sender's **boot
id** little-endian (15 bytes in all), owned by the transport: every node
broadcasts one every `KEEPALIVE_PERIOD_US` (1 s, the first one on the first
`poll()`), and additionally unicasts one to a node the moment it first
appears, so a newcomer learns everyone at once. A keepalive is learnt from,
counted in the sequence accounting of the stream its destination names and
relayed like any broadcast, and never delivered: it carries no identity and
no application sees it. The unicast one opens the stream towards the
newcomer, so it carries sequence 0.

The boot id is the identity of one run of one node, drawn at random by the
composition and handed to the constructor (`randomBootId()` on desktop, the
RNG peripheral on the board, `esp_random()` on the ESP32); it is never
derived from the chip, because what makes a node id stable is exactly what
this number must not be. `Node::boot` keeps the last one heard, 0 until the
node's first keepalive: a node id is stable across reboots, so a node that
restarts faster than `NODE_EXPIRY_US` would otherwise never leave the tables
of its peers. The first keepalive of a node sets its `boot` silently; one
carrying a different, non-zero boot id is another incarnation of the same
id, and the transport fires `onNodeDown()` then `onNodeUp()` for it with its
counters reset, so every listener drops what it knew and starts over. A node
silent for `NODE_EXPIRY_US` (3 s, three missed keepalives) is forgotten
and every `AbsPresenceListener::onNodeDown()` fires; `onNodeUp()` fires
when a node is heard for the first time. A listener attaches itself to the
transport in its constructor and detaches in its destructor, so declaring
one as a member right after the transport is the whole wiring; a transport
takes at most `MAX_LISTENERS` (4) and `init()` fails past that. A listener
may `send()` from inside its callbacks.

## Relay

Always on, nothing to switch: a frame not for this node is forwarded with
`hops + 1`, and a frame that already carries `MAX_HOPS` is dropped: a
broadcast goes out on every link but the one it arrived on; a unicast goes
out on the link its destination was last heard on, unless that is the
arrival link (split horizon) or the destination is unknown (dropped). A
node with one link therefore relays nothing, which is why no switch is
needed. The duplicate drop of the broadcast stream is what keeps a triangle
of relays from looping; a unicast that would loop is bounded by `MAX_HOPS`
alone. `Node::hops` keeps the count the last frame from a
node carried: 0 for a direct neighbour, 1 for a node behind one relay. A
relay rebuilds the last header byte rather than incrementing it in place:
the hop count shares it with the flags, which cross unchanged, so a
keepalive is relayed as a keepalive.

The hub learns the board from its keepalives, relayed by the ESP32, at the
relay's IP and data port, and its unicasts to the board land there and are
relayed down the UART; the relay's own keepalives travel beside them, from
its own node id. `relayed()` counts the frames forwarded, one per link for
a broadcast.

## Links

- `AbsLink` (`transport/link.hpp`): `send(frame, size, address)`,
  `broadcast(frame, size)`, `receive(buffer, capacity, addressOut)`, all
  non-blocking, plus `kind()` (`LinkKind::UART` or `LinkKind::UDP`, what a
  report says of the medium) and `rxErrors()`, the frames the medium could
  not deliver whole: a CRC failure or an impossible announced length on a
  serial line (`SerialFrameParser::errors()`), plus the frames larger than
  the caller's buffer, and the oversized datagrams on UDP. A stray byte
  while hunting for the sync pair is not one of them: that is the normal
  resynchronization. `LinkAddress` is a `std::variant<UartAddress, UdpAddress>`
  (an IPv4 host and port for UDP, an empty struct for a UART): the
  transport stores it per node and hands it back to the link the node was
  heard on without ever looking inside; a link reads its own alternative
  with `std::get_if` and refuses a `send()` to the other one.
- `UdpLink` (`transport/udp_link.hpp`, BSD sockets): one shared
  **discovery port** every node binds with `SO_REUSEADDR + SO_REUSEPORT`
  and only ever receives broadcasts on, and one ephemeral **data socket**
  every frame leaves from, broadcasts included, so the source port of any
  datagram is the node's unicast address. Broadcast =
  `sendto 255.255.255.255:discovery`; when the host has no route for it
  right now (an isolated container, a network that is down) the link
  falls back to `127.255.255.255`, the loopback broadcast, which Linux
  also delivers to every local listener, and tries the global address
  again on the next send; `loopbackFallback()` says it happened, and the
  application logs it (the link itself prints nothing: this library does
  not link the log library, a failed system call is a `false` from
  `init()`). `DISCOVERY_PORT` = 47820 is the one port a
  deployment must agree on; the constructor takes another one so a set of
  processes isolates itself from a live bench. `discoveryFd()` /
  `dataFd()` let a caller `poll(2)` instead of spinning. The same source
  compiles against lwIP on the ESP32 (`socket`, `bind`, `sendto`,
  `recvfrom` with `MSG_DONTWAIT | MSG_TRUNC`, `getsockname`, `close`
  through the VFS); lwIP defines `SO_REUSEPORT` but ignores it, and has no
  `getifaddrs()`, so the own-address list used for echo detection is
  filled by `addLocalHost()` there (`__has_include(<ifaddrs.h>)` picks the
  path).
- `UartLink` (`transport/uart_link.hpp`): owns no hardware, is handed an
  `AbsByteStream` (`read`, `write`) and applies the serial framing;
  resynchronizes on the sync pair after garbage or a torn frame (a torn
  frame swallows the next one up to its announced length, then the CRC
  fails and hunting resumes). Two byte streams exist: `Uart1Stream`
  (platform_stm32, the USART1 rings: `write` refuses a frame the transmit
  ring cannot hold whole, so the transport counts a drop instead of
  blocking the flight loop) and `UartStream` (`esp32-bridge/main/relay.cpp`,
  the ESP-IDF UART driver rings, same refusal rule). The tests drive it
  over an in-memory pipe (`software/tests/unit/byte_pipe.hpp`).
- `UdpLink` drops the echo of its own broadcasts (own data port, one of
  the host's addresses) before the transport sees them: a relay would
  otherwise count every frame it forwards as a duplicate of its source.

## Report

`transport/provider.hpp` and `transport/consumer.hpp` put everything above
on the wire, as the two roles every concept of the project holds. The
targets sit next to the leaf, like the log library's: `transport_provider`
and `transport_consumer`, header-only, no heap, the F405 included.

`TransportProvider` (`transport_provider`) is the handler of
`TransportSubscribe`: it answers with the `TransportSubscription` it
holds, at most `MAX_SUBSCRIBERS` (2) of them, and `tick(nowUs)` sends one
`TransportReport` every `REPORT_PERIOD_US` (1 s) to each. With no
subscriber nothing is packed at all. One report is this node's view of the
wire: the transport's own counters, the messenger's, one entry per link
(kind, the `LinkStats`, `rxErrors()`) and the peer table. That table does
not fit one frame, so it travels by pages of `PEERS_PER_PAGE` (4) peers,
all of them in the same tick, every page carrying the counters again and
naming the slice it holds (`peer_cursor`, `peer_total`). Everything is
cumulative and never a rate: a lost report skews nothing, whoever reads
takes the differences. `fillPage()` is public, so a node that consumes its
own report walks the pages without the wire.

`TransportConsumer<N>` (`transport_consumer`) is the other side. It is an
`AbsDirectoryListener`: an identity of a kind that carries a provider
(`FIRMWARE`, `DRONE_SIM`, `RELAY`, `GATEWAY`) with a matching wire hash
opens an entry, and `setWanted(true)` subscribes to every entry open now
and later. `setWanted(false)` unsubscribes and forgets the reports held,
so nothing stale is published. The pages of one report are merged into one
peer table, and the entry becomes the report when the last page arrives:
a page with cursor 0 always opens a new merge, and a page whose cursor is
not where the merge stood is dropped, which abandons that report and
starts over on the next one. An `AbsTransportConsumerListener` (at most
`MAX_LISTENERS`, 2) hears `onReport()` and `onForgotten()`. A node that
consumes its own report has no wire to itself: `openLocal(id)` opens the
entry and `accept()` feeds it the pages directly.

## GDScript port

`sim-godot/scripts/transport/transport.gd` (`Mark4Transport`) is the same
transport for the Godot plant: the same header, the same node table and
counters, the same keepalive and expiry rules, the same sequence per stream
and its duplicate drop, no relay. Its two sockets follow the `UdpLink` layout, with one
substitution forced by the engine: Godot's `PacketPeerUDP.bind()` sets no
reuse option, so the discovery socket is a `UDPServer` (`listen()` sets
`SO_REUSEADDR`, which is enough on Linux to share the port with the
`SO_REUSEADDR + SO_REUSEPORT` sockets of the C++ nodes). The plant hosts
one virtual drone per node whose identity says `DRONE_SIM`, and the lockstep
exchange (`SimSensor`, `SimActuator`, `SimScenario`) is unicast frames
between the plant's node id and each `drone_sim`'s: `drone_sim` adopts as
its plant the first node whose `SimSensor` validates, until the transport
forgets it (`platform_sim/plant_link.hpp`). Nothing is configured, no
port is reserved. `sim-godot/scripts/transport/discovery.gd`
(`Mark4Discovery`) is the port of `discovery/` next to it: it asks every
node the transport learns who it is, with the same timeout and retries,
and answers the plant's own identity to whoever asks.
`sim-godot/tests/transport_check.gd` is the transport's ctest smoke,
`test_plant_link.cpp` exchanges frames with it from C++.

## Ports

| port | who | what |
|---|-----|---|
| udp/47820 | every transport node | discovery: the broadcast keepalives, and nothing else |
| ephemeral | every transport node | data socket: every unicast frame (streams, commands, answers, the lockstep sim link, the keepalive on first sight) |
| udp/47810 | hub | HTTP + WebSocket for the pages |

The ESP32 relay owns no port of its own: it is one more node on udp/47820
with an ephemeral data socket, and the board's UART carries transport
frames in the serial framing. It shares the address the board is seen at:
two node ids, one IP and one data port.

`drone_sim` and the firmware send telemetry, log lines, the `Status`
report and every answer (tuning, OTA) as unicasts to the node that asked
or subscribed; commands reach them as unicasts to their node. The
keepalive is the one broadcast left, and it carries the sender's boot id
and no identity: who a node is travels only as the answer to an
`IdentityRequest` (`software/components/discovery/`). The board's node id
is `hashNodeId()` of the 96-bit MCU unique
id (`boardNodeId()`), so it survives resets and reflashes.

## Open points

- No retransmission, no acknowledgement, no fragmentation: what the
  application needs it does above. The messenger
  (`software/components/messaging/`) numbers, keeps and resends what has to
  arrive and acknowledges what it receives; the OTA session has its own
  go-back-N on top of that.
- The board's transport keeps the full `MAX_NODES` = 32 table (about
  1.3 KB) although it only ever sees a handful of nodes; RAM is not tight
  on the F405 so nothing shrinks it.

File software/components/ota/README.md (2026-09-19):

# ota

The firmware update brick of every node that carries two firmware slots:
the flight controller, the desktop flight process (with files for slots)
and the ESP32 relay. It is a node brick like `log` and `transport`, not a
flight service: the platform layer is the abstract services of the flight
loop, and an update is what happens when the loop is parked. Header-only
target `ota`, `protocol/` alone underneath, no heap, no iostream, no
exceptions, so the same headers compile for the F405, for the ESP32 (which
builds `software/components/` sources as they are) and for the desktop;
its `src/` holds one single-include source per header, the file that
compiles the header alone and that the editor's language server takes the
header's flags from. The ground side of the same concept lives here too
(`ota_consumer`), desktop only and under its own rules, described at the
end of the list below. `docs/ota-design.md` is the reference for every
decision below.

## What is here

- `ota/firmware_store.hpp` - `AbsFirmwareStore`, the interface every
  updater drives: slot geometry, erase, program in order, read back, CRC,
  the boot metadata (`OtaMetaState`, read and append), plus the two image
  reads that depend on the image format of the chip: `imageValid()` and
  `readIdentity()`. Implementations stay with their targets:
  `platform_stm32/firmware_store_stm32.hpp` (internal flash),
  `platform_sim/firmware_store_sim.hpp` (files in a directory),
  `esp32-bridge/main/firmware_store_esp32.hpp` (ESP-IDF partitions).
- `ota/updater.hpp` - `OtaUpdater`, the board-side session: one `Ota*`
  message in, at most one reply out, the refusal policy, the go-back-N
  transfer, the staging record, the self-confirmation of a trial image on
  its first ground contact. Pure logic against the store, unit-tested on
  the desktop with fault injection (`software/tests/unit/test_ota_updater.cpp`).
- `ota/boot_policy.hpp` - the slot decision of a reset and the arming
  interlock, pure functions of an `OtaMetaState`. `drone_boot` and
  `drone_sim`'s fake trial boot run this very code.
- `ota/meta_log.hpp` - `OtaMetaLog`, the append-only record log over two
  erase-together areas: newest valid record wins, ping-pong when one area
  fills. Shared by the bootloader, the stm32 store and the sim store.
- `ota/image_header.hpp` - the `OtaImageHeader` reads of the two stores
  whose slots open with that header (stm32, sim): validity of a flashed
  image and its build identity.
- `ota/provider.hpp` - `OtaProvider`, the updater on the wire (target
  `ota_provider`, over `messaging`): an `AbsMessageHandler` that hands each
  `Ota*` request to the updater and sends its reply, when there is one, to
  the node that asked. The replies go out with `send()` rather than
  `request()`: the session has its own go-back-N and its own retries, and a
  reply resent by the messenger would answer a step the session has left.
  `consumed()` counts the requests the updater consumed, so a composition
  that caches something an update may change (the arming interlock read off
  the boot metadata) re-reads it when the count moves rather than on every
  frame.
- `ota/gate.hpp` - `AbsOtaGate`, the two facts the updater asks of the node
  before it lets a session in: whether the motors may spin and whether the
  pack is above the update floor. `ota/flight_gate.hpp` is the gate of a
  node that flies (`FlightOtaGate`, target `ota_flight_gate`, the one
  header here that knows a `FlightCore` exists); a node that does not fly
  writes its own two-line gate and carries the provider without a flight
  core.
- `ota/crc32_mpeg2.hpp` - the one checksum of the update system, software,
  bit for bit what the F405 hardware CRC unit computes over the same words.
  The hub uses this very code on the bundle.
- `ota/bundle.hpp` + `ota/consumer.hpp` - the ground side: the `.ota` bundle
  a firmware build produces, read and validated off a filesystem, and
  `OtaConsumer`, the session state machine that drives one board through the
  transfer, the trial boot and the confirmation. It owns no socket, no
  thread and no clock: it is fed instants by `tick()`, messages by
  `onEnvelope()` and emits through a `MessageSink` the composition binds.

  These two are the one exemption to the rules at the top of this page.
  They read a file and keep the `std::string` and `std::function` they were
  written with, so they are a static library (`ota_consumer`) declared only
  where the desktop platform is configured, the way `platform_sim` is: the
  one ground node of the project is a desktop process. Nothing of them
  compiles for the F405 or the ESP32, and nothing of the headers above
  depends on them.

## Two image formats behind one updater

An F405 slot opens with the 512-byte `OtaImageHeader` of
`protocol/ota_image.hpp`, stamped by `scripts/make_ota.py`. An ESP32 slot
holds a raw ESP-IDF application image: the IDF bootloader parses that
format and no other, so there is no `OtaImageHeader` to read there. The
updater therefore never reads an image itself. When a transfer completes it
asks the store whether the slot now holds an image of the announced size
built for this chip and this slot (`imageValid()`), and when it reports the
status it asks the store for each slot's build epoch and git hash
(`readIdentity()`). The stm32 and sim stores answer out of the header
prefix (`ota/image_header.hpp`); the esp32 store out of the IDF image
header and its `esp_app_desc_t`.

The metadata is the same story: the stm32 and sim stores persist
`OtaMetaState` through `OtaMetaLog`, the esp32 store synthesizes it from
what the IDF bootloader keeps in its `otadata` partition and translates
each write into the matching IDF call (set boot partition, cancel
rollback). The updater does not know which.

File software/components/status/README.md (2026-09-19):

# status

What a drone is doing, as the wire says it. A header-only target
(`status_provider`) over `messaging` (the dispatch and the sender),
`flight_core` (the state read) and `log`; no heap, no iostream, no
exceptions, no RTTI, and it builds for the F405 as it stands. Its `src/`
holds one single-include source per header: the file that compiles the
header alone and that the editor's language server takes the header's
flags from.

## What Status is

`Status` is the small fixed report of what the drone is doing, not a
measurement stream. Fixed content: attitude, motors, phase, throw state and
count, the two validity flags, the RC link flag, and the plant truth when
the composition has one. It answers "where is it and is it healthy", which
is what a control page and an attitude view need on every frame they paint.

A quantity that belongs to one module rather than to every consumer is
registered as a telemetry measure instead
(`software/components/telemetry/README.md`): the registry is where a new
number goes, and a field is added to `Status` only when every consumer of
`Status` needs it.

## The packer

`status/status_packer.hpp` holds `packStatus()`, an IO adapter that reads
only public accessors of the flight core, so flight-core never sees a wire
type. It is also where the flight core enums and their wire counterparts
are pinned to each other, value by value.

## The provider

`status/status_provider.hpp` holds `StatusProvider`, an
`AbsMessageHandler` of the composition's `Messenger`:

```cpp
StatusProvider statusProvider{messenger};          // a member after the messenger
statusProvider.publish(frame, actuators, core, rcLinkOk, truth);  // once per flight frame
```

It consumes `StatusSubscribe`. A node that subscribes is added to the table
and answered with a `StatusSubscription`, the subscription the node holds
afterwards; `enabled` comes back false when the table is full or when the
request was an unsubscribe. A request and its answer are two message types,
never one, so a node that is both provider and consumer of the concept
claims a different body tag on each side. A node that goes down is dropped
(`onNodeDown()`), so a consumer that crashed leaves nothing streaming
behind it.

`publish()` counts the frames and packs one report every
`STATUS_PERIOD_FRAMES` = 10, so a 500 Hz loop reports at 50 Hz. The
provider owns that counter, so every composition decimates the same stream
the same way. With no subscriber nothing is packed at all. The reports go
out with `send()`: a report is only worth its own instant, and the next one
is ten frames away.

`MAX_SUBSCRIBERS` = 4. It is small on purpose: one emission per entry, and
a board's UART pays every one of them at 50 Hz, next to the log lines and
the telemetry stream sharing the same line. The provider never reads a
clock: `publish()` takes the frame's own timestamp through the frame.

## The consumer

`status/consumer.hpp` holds the other side of the same concept, for a
ground node: `StatusConsumer<N>`, an `AbsMessageHandler` and an
`AbsDirectoryListener` at once, sized by the composition
(`StatusConsumer<Transport::MAX_NODES>` on the gateway). It is header-only
like the provider, fixed tables, no heap.

```cpp
StatusConsumer<Transport::MAX_NODES> status{messenger, directory};  // after both
```

The kinds that carry a `StatusProvider` are its own constant (`KINDS`:
`FIRMWARE`, `DRONE_SIM`), so the composition names no kind. A node of one
of those kinds whose announce matches this wire hash is opened from
`onIdentity()`: one entry, one `StatusSubscribe { enabled: true }` sent
with `request()`, and the `StatusSubscription` that answers says whether the
node took it. Every
report is stored and handed to the listeners
(`AbsStatusConsumerListener::onStatus()`); a node that goes down loses its
entry and the listeners hear `onForgotten()`. A reincarnation is a node
down, a node up and a fresh identity, so it opens itself again.

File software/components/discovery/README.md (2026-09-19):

# discovery

Who is who on the wire. A static library over `messaging` (the dispatch
and the sender, which bring `transport` and `protocol` with them), no heap,
no iostream, no exceptions, no RTTI, and it builds for the F405 as it
stands. Two classes: `Discovery`, the handler every node carries, answers
an `IdentityRequest` of `protocol/mark4.proto` with the node's `Announce`;
`DiscoveryDirectory`, for a node that also needs to know who is around,
asks every node the transport hears, retries on a timeout, gives up after a
few, and keeps the answers by kind. `drone_sim`, the firmware and the ESP32
relay carry a `Discovery`; the hub carries a `DiscoveryDirectory`. The
Godot plant and the phone hold ports of both in their own languages
(`sim-godot/scripts/transport/discovery.gd`,
`software/mobile/lib/back/discovery/`), so every node of the system
answers who it is.

## Identity

Presence on the wire is the transport's keepalive, which carries the
sender's boot id and no identity. What a node is (its kind, its name, its
MCU, the
build it runs, the schema it speaks) travels only on request: whoever
wants to know sends an `IdentityRequest`, unicast, and the node answers
with its `Announce`, unicast, to the requester. Nothing is broadcast and
nothing is sent unsolicited. A node that cannot say who it is does not
exist for the ground tools.

```cpp
class Discovery : public AbsMessageHandler
{
  public:
    static constexpr std::array<pb_size_t, 1> TAGS = {mark4_Envelope_identity_request_tag};
    Discovery(Messenger &messenger, const mark4_Announce &self);   // self is copied
    bool onMessage(std::uint32_t src, const mark4_Envelope &envelope, std::uint64_t nowUs) override;
    const mark4_Announce &self() const;
    std::uint32_t answered() const;                                 // requests answered
};
```

Declared as a member after the messenger, it is wired: `onMessage()` sends
`self` to `src` as a request of its own (the answer that matters is
acknowledged like everything that has to arrive) and counts. The composition builds the `Announce` once,
from what it knows of itself (`drone_sim`: kind `DRONE_SIM`, mcu `SIM`,
`WIRE_HASH`, no build identity since a process is not a packaged image).

## Directory

`DiscoveryDirectory` is a `Discovery` (it answers too) that hears presence
through the messenger, like every handler. A node that appears gets an entry
`PENDING`; the next `tick()` asks it, once, with the policy
`{IDENTITY_TIMEOUT_US, IDENTITY_RETRIES}`: the resends every 500 ms and the
giving up after 5 sends are the messenger's, and when it gives up
`onRequestFailed()` moves the entry to `MUTE` and leaves it alone. An
`Announce` from the node, at any time, makes the entry `KNOWN`: the announce
is stored, the `wireMismatch` flag compares its `wire_hash` with this
build's `WIRE_HASH`, `hops` is read from the transport's node. A node the
transport expires takes its entry with it.

```cpp
struct DirectoryEntry
{
    enum class State : std::uint8_t { PENDING, KNOWN, MUTE };
    std::uint32_t id;                 // node id
    State state;                      // PENDING: asked, no answer yet; KNOWN: announce valid; MUTE: gave up
    mark4_Announce announce;          // valid when KNOWN
    bool wireMismatch;                // KNOWN and announce.wire_hash != WIRE_HASH
    std::uint8_t hops;                // relays between this node and it
    std::uint64_t askedUs;            // instant the request was started
    std::uint8_t requests;            // requests started, 0 or 1: the resends are the messenger's
    std::uint64_t updatedUs;          // instant of the last state change
};

DiscoveryDirectory directory(messenger, transport, self);   // after the messenger, whose presence events it takes
directory.init();                                           // false past MAX_LISTENERS listeners
directory.tick(nowUs);                                      // once per loop, after messenger.poll()
directory.find(id); directory.size(); directory.entry(i);   // the table, a dense prefix in no particular order
directory.nodesOfKind(kinds, out);                          // the KNOWN entries of those kinds, copied into out
directory.requests(); directory.learnt(); directory.muted(); directory.dropped();
```

The directory never reads a clock. `onNodeUp()` has no instant and sends
nothing: it creates the entry with no request behind it, and `tick()` asks
at once. A request is counted whether or not the messenger took it: a full
pending table refuses it, and the next tick asks again. `MAX_ENTRIES` is the transport's `MAX_NODES`; a node that
appears while the table is full is counted in `dropped()` and gets its
entry from its `Announce` if one ever arrives (a node the transport learnt
before the directory existed is handled the same way).

## Listeners

```cpp
class AbsDirectoryListener
{
  public:
    explicit AbsDirectoryListener(DiscoveryDirectory &directory);   // attaches
    virtual ~AbsDirectoryListener();                                // detaches
    virtual void onIdentity(const DirectoryEntry &entry) = 0;      // KNOWN now, or the announce changed
    virtual void onForgotten(std::uint32_t nodeId) = 0;            // the transport expired the node
};
```

Same shape as `AbsPresenceListener`: a fixed table of `MAX_LISTENERS`
(8), attached in the constructor and detached in the destructor, `init()`
false for as long as one past the table lives. `onIdentity()` fires when
an entry becomes `KNOWN` and again when a later `Announce` differs from
the stored one (field by field; a node that rebooted on another build);
an identical answer is silent. The notifications run from inside
`onMessage()` and `onNodeDown()`, so a listener may `send()` from them,
as it may from a presence callback.

## Counters

| counter | meaning |
|---|---|
| `answered()` | `IdentityRequest`s answered with `self` |
| `requests()` | `IdentityRequest`s started, the refused ones included; what the messenger resent is its own counter |
| `learnt()` | `Announce`s stored as an identity |
| `muted()` | nodes whose request ran out of sends |
| `dropped()` | nodes that appeared while the table was full |
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

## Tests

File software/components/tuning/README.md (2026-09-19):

# tuning

The tunable parameters of the flight core on the wire. A header-only
target (`tuning_provider`) over `messaging` (the dispatch and the sender),
`flight_core` (the registry) and `log`; no heap, no iostream, no
exceptions, no RTTI, and it builds for the F405 as it stands. Its `src/`
holds one single-include source per header: the file that compiles the
header alone and that the editor's language server takes the header's
flags from.

## The provider

`TuningProvider` (`tuning/provider.hpp`) is an `AbsMessageHandler` of the
composition's `Messenger`, declared as a member after it. flight-core never
includes a wire header, so this is where the two vocabularies meet: the
`TuningStatus` values and the parameter name width are pinned to the wire
here, one `static_assert` each.

Three messages reach it, each answered to the node that asked:

- `TuningSet { id, value }` and `TuningGet { id }`, answered by a
  `TuningAck { id, value, status }`. The value that travels is always the
  live one, whatever the outcome: a refused write is answered with what is
  still flying, so a ground tool never has to guess what it ended up with.
- `TuningListRequest { cursor }`, answered by one `TuningInfos { total,
  cursor, infos }` page of at most `INFOS_PER_PAGE` descriptions. The
  consumer paces the walk, one page per request, and the last page is the
  one where `cursor + infos_count == total`. A cursor past the end comes
  back as an empty page carrying the total.

Every answer goes out with `request()`: an answer that matters is a
request of its own, acknowledged on arrival and resent until it is. The
page shape is what the UART wanted: a board that answered a list request by
dumping the whole table at once would flood a 921600 baud line for
milliseconds and starve the telemetry stream sharing it.

## Timing

`onMessage()` runs inside `Messenger::poll()`, which every composition runs
before `FlightCore::step()`: a value a request writes is in effect for the
whole of the next step and never changes one halfway through. The core is
single-threaded and so is this: no locking, no queue, and no clock read.

## The consumer

`tuning/consumer.hpp` holds the other side of the same concept, for a
ground node: `TuningConsumer<N>` (target `tuning_consumer`), an
`AbsMessageHandler` and an `AbsDirectoryListener` at once, sized by the
composition. Header-only, fixed tables, no heap.

```cpp
TuningConsumer<Transport::MAX_NODES> tuning{messenger, directory};  // after both
tuning.set(node, id, value);   // also get(), refresh()
```

The kinds that carry a `TuningProvider` are its own constant (`KINDS`:
`FIRMWARE`, `DRONE_SIM`). A node of one of those kinds whose announce
matches this wire hash is opened from `onIdentity()` and its table pulled
with a `TablePull<mark4_TuningInfo, MAX_PARAMS>`: one
`TuningListRequest` per page, the next asked for as each page lands, the
listeners told once the table is whole
(`AbsTuningConsumerListener::onTable()`). A `TuningAck` reaches
`onResult()`, and a write that went through moves the value in the table,
so what the consumer holds is what flies. A page request given up on
abandons the walk; a node that goes down loses its entry.

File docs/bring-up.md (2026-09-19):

# Board bring-up - mark1 hardware

Reference for running the firmware on real hardware: the custom mark1
flight controller, a reflashed ST Discovery as debug probe, and a
commercial IMU breakout. Everything runs from the devcontainer.

## Hardware

### Flight controller: mark1

Custom board (schematics and docs: https://github.com/Keyrim/drone-stm32f4-mark1,
see `Flight_Controller/Board/Docs/Flight_Controller_Schematic.md`).

- **STM32F405RGT6**, 8 MHz HSE crystal - the exact chip the `stm32`
  preset, `startup.c` and `stm32f405_image.ld.in` already target.
- **BOOT0 tied to GND**: no USB, no DFU. Flashing goes through SWD only.
- LDO 5V -> 3V3 (MCP1826). Status LEDs: LED1 = PC13, LED2 = PC14.
  **LED2 is dead on this unit** (PC14 measures 3.3 V on IDR when driven,
  the LED never lights: dead, reversed or never fitted): all the LED
  signalling goes through LED1 (see `software/drone_firmware/status_leds.hpp`).
- `Prog` header, 6 pins: `3V3, SWCLK, GND, SWDIO, NRST, SWO` - the same
  pinout as the CN2 connector of ST Discovery boards, so the probe cable
  is 1:1.
- UART1 on PB6/PB7 (connector `uart1`), UART3/UART4 free, UART6 on the
  GPS connector. I2C1 on PB8/PB9 with 4.7k pull-ups on the board.

### Power

The mark1 Power board was never produced. The board is powered through
an **FTDI USB-UART dongle**: its 5V goes into the `+5` pin of a UART
connector, which feeds the 5V rail and the LDO. The same dongle carries
the UART telemetry.

### Sensors

The mark1 Sensors board is not used. Commercial breakouts (identified on
the bus by the bring-up firmware) are wired to the `sensor_board`
connector and share **I2C1**: a **GY-86** for the IMU and compass, and an
**Adafruit BMP581** for the pressure:

- **MPU6050** at 0x68 (confirmed by WHO_AM_I).
- The barometer of the GY-86 (an MS5611 at 0x77) was faulty: the I2C
  protocol answered but the solved pressure was negative, so the driver
  gated every solution and the frame carried 0 Pa. It has been replaced
  by an **Adafruit BMP581 breakout** on the same bus; the driver probes
  both of its addresses (0x46 with SDO low, 0x47 with SDO high) and
  locks onto whichever answers with the chip id. A barometer that fails
  to come up is not fatal: the firmware boots without it and the frames
  carry 0 Pa, which is visible in the telemetry from the ground.
- **HMC5883L** compass at 0x1E, wired behind the MPU6050 auxiliary bus:
  it only appears on the main bus once the MPU I2C bypass
  (INT_PIN_CFG.I2C_BYPASS_EN) is open.

Constraints this hardware puts on the firmware:

- The MPU interrupt line is **not wired**: the main loop is paced by a
  timer interrupt (WFI on the timer), not by the gyro data-ready. The
  SensorFrame timestamp comes from that timer.
- The MPU6050 gyro saturates at +/-2000 deg/s (~35 rad/s): the flight
  core's gyro saturation cutoff must sit below that, and saturation must
  be handled. Measured hand throws tumble at <= 10 rad/s, well within
  range.

## Debug probe

An old ST Discovery reflashed to a **J-Link OB** (SEGGER STLinkReflash).
Remove the two ST-LINK jumpers (CN3) so the probe drives the external
target instead of the on-board MCU, then wire CN2 to the `Prog` header
pin for pin.

## Container access to the probe

The probe and the FTDI dongle are attached to WSL, then reach the
container through the `/dev` bind mount (see `.devcontainer/`):

```powershell
# Windows side, once per plug-in
usbipd list
usbipd attach --wsl --busid <BUSID>
```

The J-Link tools live in the image (`/opt/SEGGER/JLink`). The usbipd
device node comes up root-only, which blocks the J-Link tools as the
container user. Persistent fix, once in the WSL distro (udev runs there,
not in the container; the rules file is extracted in the image):

```sh
# WSL side (grab the file from the container, then reload udev)
docker cp <container>:/etc/udev/rules.d/99-jlink.rules /etc/udev/rules.d/
sudo udevadm control --reload-rules
# then detach / re-attach the probe with usbipd
```

Quick one-shot alternative, from inside the container (the /dev bind
mount makes it act on the WSL node, lost at the next re-plug):

```sh
sudo chmod 666 /dev/bus/usb/<bus>/<dev>
```

## Flash and logs

```sh
# Build
cmake --preset stm32 && cmake --build --preset stm32

# Flash (J-Link commander)
JLinkExe -device STM32F405RG -if SWD -speed 4000 -autoconnect 1
# then: loadfile software/build/stm32/drone_firmware/drone_firmware.elf, r, g

# Or: gdb server + gdb
JLinkGDBServer -device STM32F405RG -if SWD -speed 4000 &
gdb-multiarch software/build/stm32/drone_firmware/drone_firmware.elf \
    -ex "target extended-remote localhost:2331"

# RTT console: the RttSink of the log library writes every line the
# board's modules let through ("t_ms LEVL module: text"); the same lines
# leave as Log frames through the ESP32 relay, so the hub sees them without
# a probe. Periodic status lines are DEBUG: raise app/status from a client.
JLinkRTTClient
```

## Bring-up sequence

Incremental, one observable win per step:

1. **Clock + heartbeat + RTT + I2C scan**: 168 MHz from the 8 MHz HSE,
   LED1 blinking, a hand-written RTT up-buffer for logs, and an I2C1
   scan printing the addresses found on the breakout.
2. **IMU driver**: MPU6050 over I2C, timer-paced sampling into
   SensorFrames; barometer driver for whatever the scan identified.
3. **Telemetry**: SensorFrames streamed over UART1 to the PC. Done: the
   board is a transport node (`software/components/transport/`) with one
   `UartLink` on USART1 at 921600 baud, node id hashed from the MCU unique
   id. Its keepalive makes it visible, and it answers an `IdentityRequest`
   with the `Announce` naming the board, its chip, its build and its wire
   hash; it emits a 50 Hz `Status` stream and its `Log` lines (init
   failures, update state changes; at most 50 per second) to the ground
   nodes that subscribed to them, and its tuning and updater answers to
   whoever asked, so a bench without a probe reads them in the hub. Every
   frame is the transport header then the envelope,
   inside the serial framing of `transport/serial_framing.hpp` (a UART has
   no datagram boundaries), interrupt-driven behind a ring buffer; a frame
   the transmit ring cannot hold is dropped whole and counted. The other
   end of the UART is the ESP32 relay riding the drone (`esp32-bridge/`):
   a transport node that relays between its two links: the board's
   unicasts onto the WiFi LAN and, down the UART, the unicasts for the
   board and the LAN's keepalives. The `hub` sees the board as one more
   node of the LAN (kind `firmware` once it answered who it is, at the
   relay's address) and the
   Connections panel of the control page connects to it with the same
   click as to `drone_sim`. The uplink carries the pilot state
   (`Rc`: kill, arm, mode, throttle and the three sticks): a pilot input
   aimed at the board on the hub websocket endpoint becomes one `Rc`
   unicast from the gateway's own node to the board's, and 200 ms of
   silence trips the
   fail-safe (kill engaged, disarmed), so closing the sender is itself a
   safe action. A simulated
   flight is flown the same way, aimed at `drone_sim`
   instead, so the RC path and its
   fail-safe are exercised in every simulated flight, not only on the
   bench. The simulator holds no pilot state of
   its own - it is the plant, not the cockpit - and its keyboard only
   drives the view (which drone is followed, from which camera); resets
   and throws are scenarios sent to the flight process by the console
   page or the phone. A reboot command on the endpoint becomes one `Reboot`
   request the gateway unicasts to the board, acknowledged on arrival
   before the NVIC system reset;
   no simulator key is wired to it.
4. **Detection on real hands**: board armed and shaken in hand (no
   false spin-up expected), then thrown and caught - throw detection
   and apex prediction on real sensor data, compared against the
   simulated runs.

No vendor HAL: the register map comes from the vendored CMSIS device
header (`software/third_party/cmsis`), and only the peripherals actually
in use are touched. The old mark1 firmware (`Flight_Controller/Software/`)
is a register-map reference, not a dependency.

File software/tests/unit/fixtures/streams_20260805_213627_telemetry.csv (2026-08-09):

timestamp_us | gyro_x | gyro_y | gyro_z | quat_w | quat_x | quat_y | quat_z | bias_x | bias_y | bias_z | motor_0 | motor_1 | motor_2 | motor_3 | altitude_m | vz_mps
2634000 | 0.002130528911948204 | -0.002130528911948204 | 0.0 | 1.0 | 5.409770164988004e-05 | -4.651167182601057e-05 | -1.2784727005055174e-05 | -3.705531980813248e-06 | 2.305193447682541e-06 | 4.736146475003977e-10 | 0.0 | 0.0 | 0.0 | 0.0 | 0.0 | 0.0
2654000 | 0.002130528911948204 | -0.004261057823896408 | -0.002130528911948204 | 1.0 | 0.00013971890439279377 | -7.810247188899666e-05 | -4.2621089960448444e-05 | -1.1621116755122785e-05 | 2.903615495597478e-06 | 1.8668462331561386e-09 | 0.0 | 0.0 | 0.0 | 0.0 | 0.0 | 0.0
2674000 | 0.0 | -0.002130528911948204 | -0.004261057823896408 | 1.0 | 0.0002134310925612226 | -5.842106475029141e-05 | -5.9681013226509094e-05 | -1.8125308997696266e-05 | -1.8341337408855907e-06 | 4.188721813846996e-09 | 0.0 | 0.0 | 0.0 | 0.0 | 0.0 | 0.0
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

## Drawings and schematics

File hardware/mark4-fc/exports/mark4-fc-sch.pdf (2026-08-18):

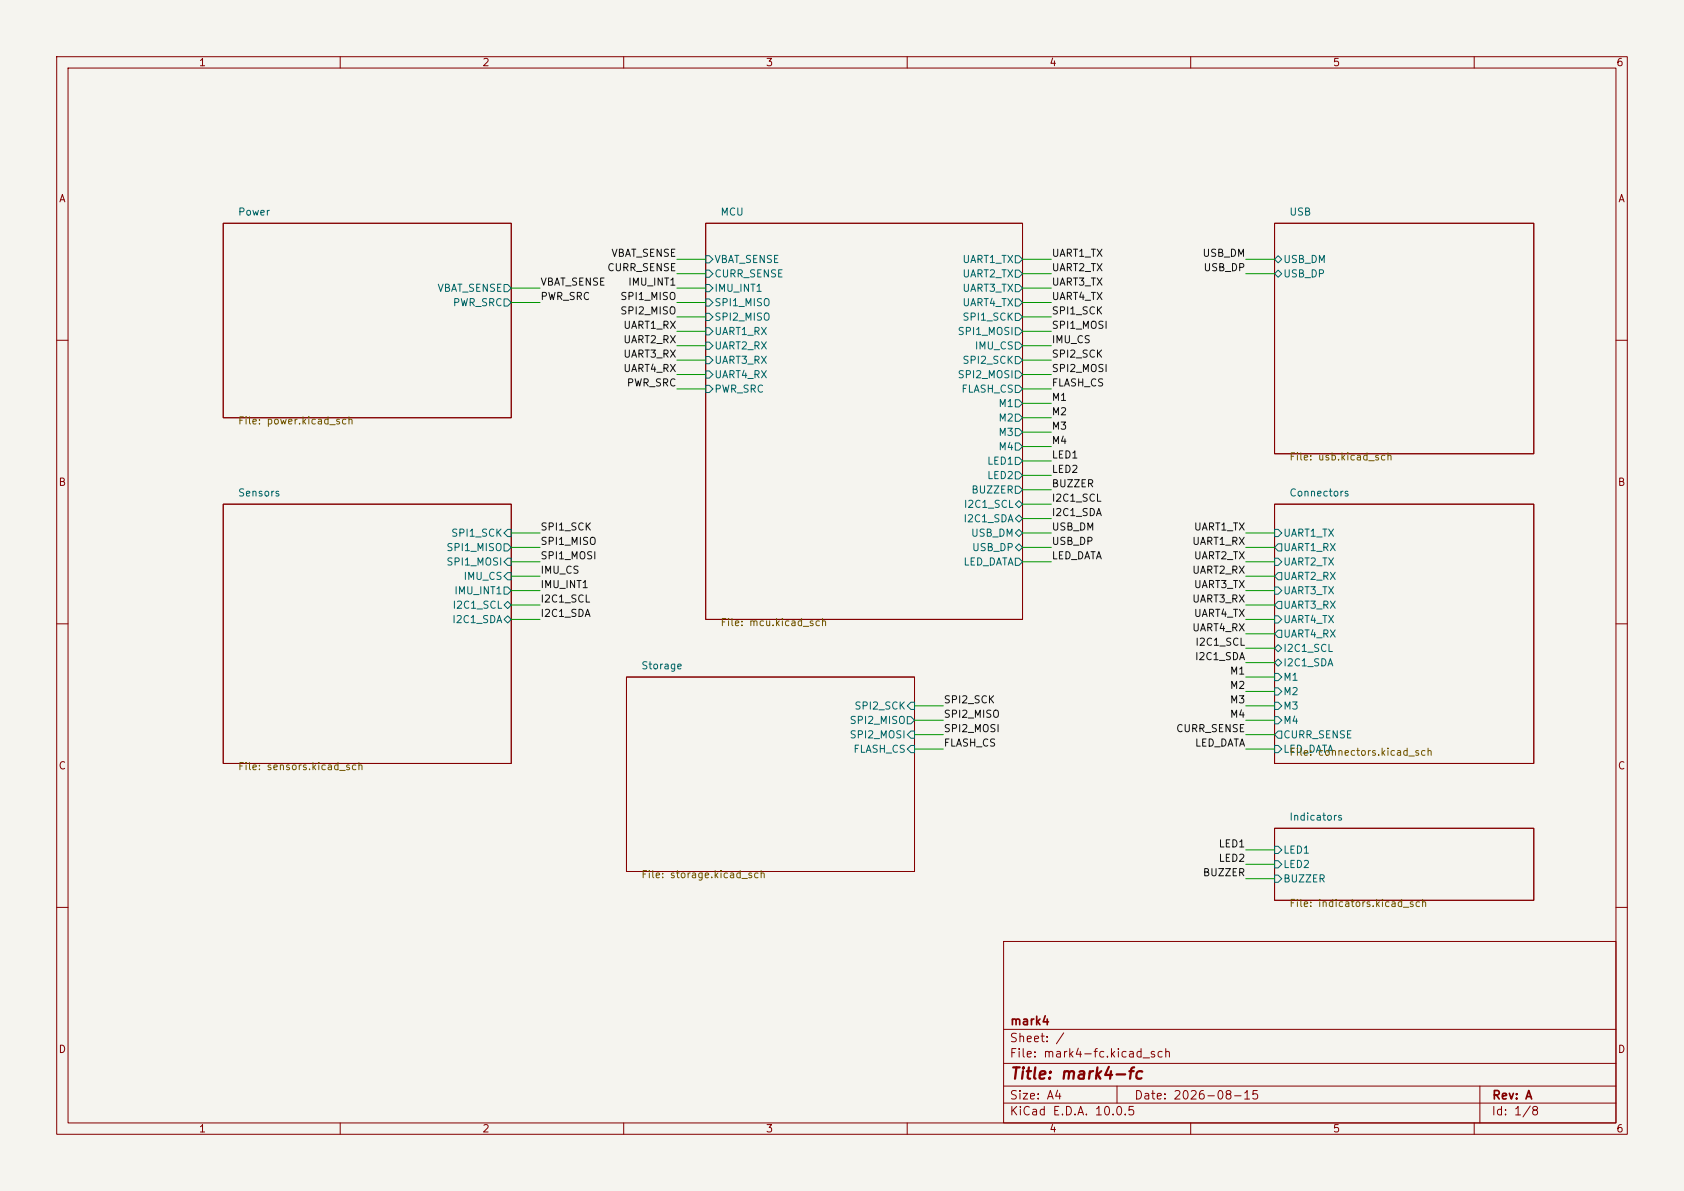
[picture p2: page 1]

Size: A4 | Rev: A
KiCad E.D.A. 10.0.5 | Id: 1/8

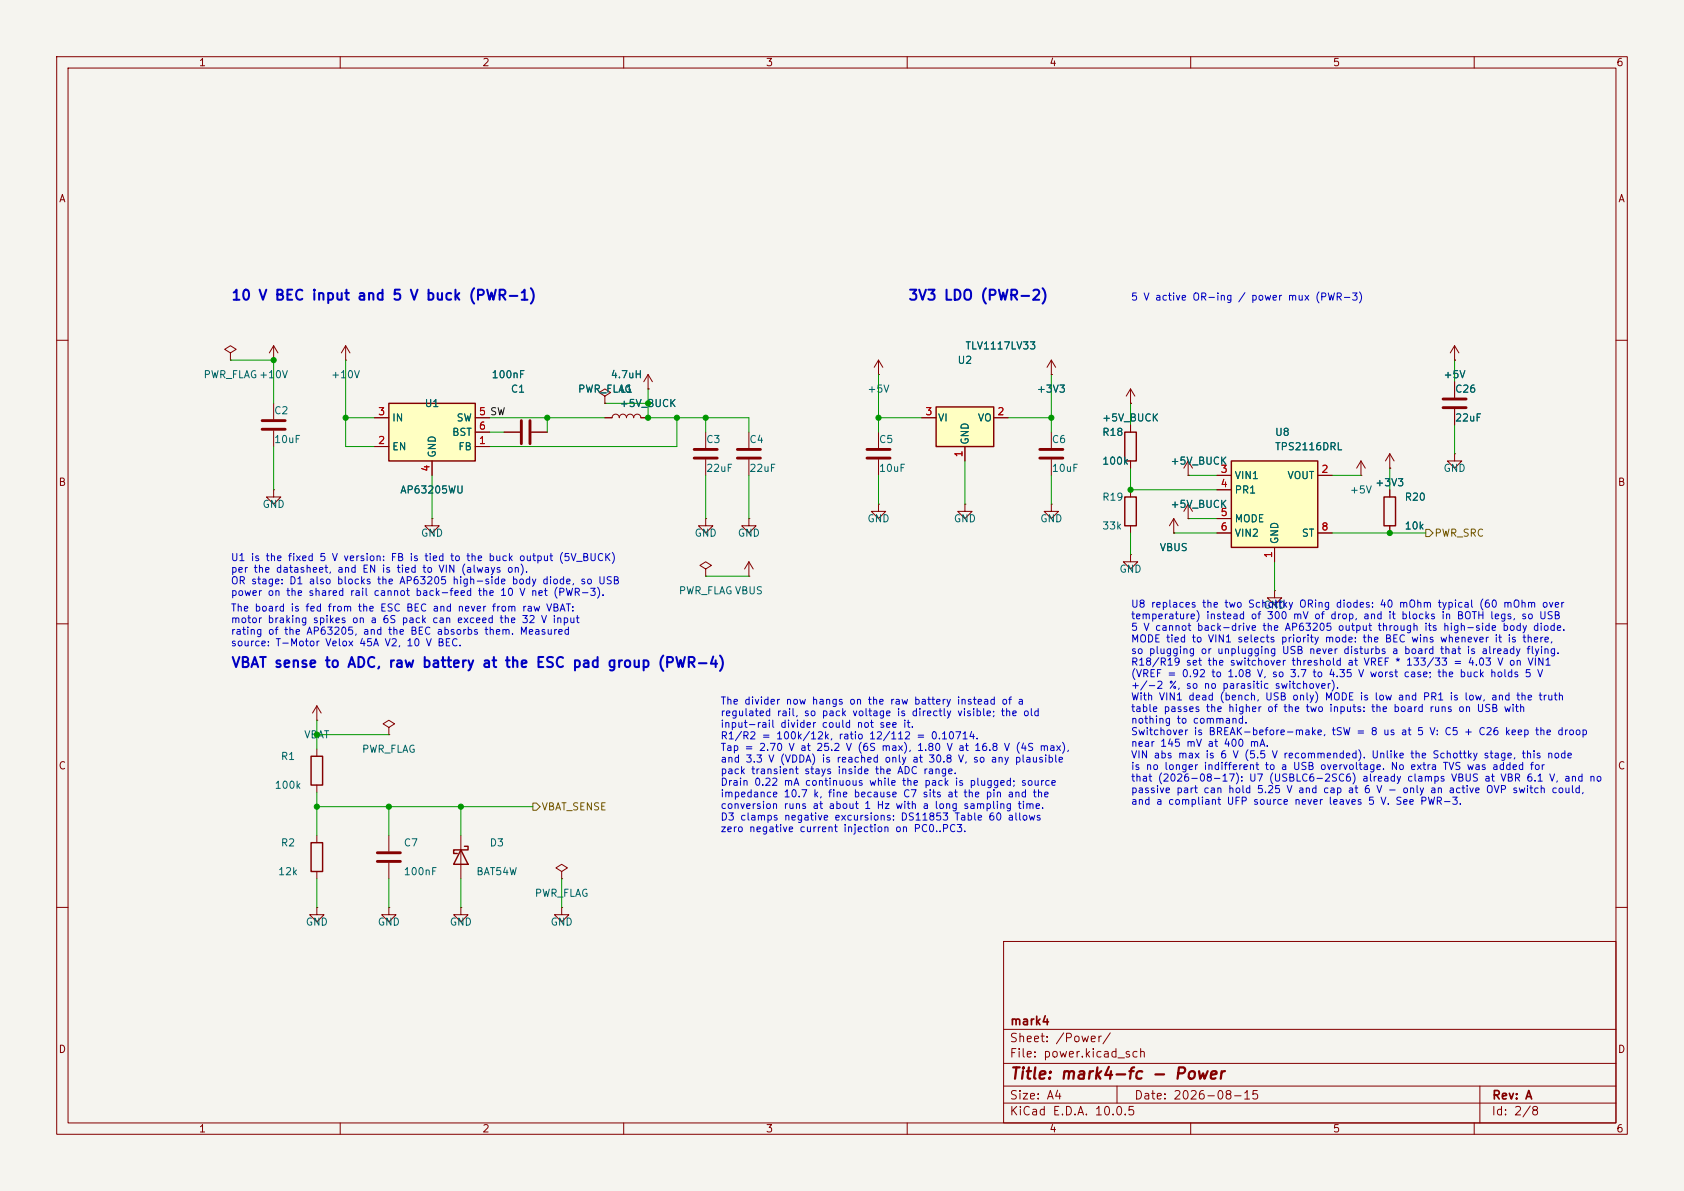
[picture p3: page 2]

5 V active OR-ing / power mux (PWR-3) The board is fed from the ESC BEC and never from raw VBAT: motor braking spikes on a 6S pack can exceed the 32 V input

zero negative current injection on PC0..PC3. U2

source: T-Motor Velox 45A V2, 10 V BEC. VBAT sense to ADC, raw battery at the ESC pad group (PWR-4) U1 is the fixed 5 V version: FB is tied to the buck output (5V_BUCK) per the datasheet, and EN is tied to VIN (always on). OR stage: D1 also blocks the AP63205 high-side body diode, so USB

power on the shared rail cannot back-feed the 10 V net (PWR-3).

temperature) instead of 300 mV of drop, and it blocks in BOTH legs, so USB
5 V cannot back-drive the AP63205 output through its high-side body diode. MODE tied to VIN1 selects priority mode: the BEC wins whenever it is there, so plugging or unplugging USB never disturbs a board that is already flying.

rating of the AP63205, and the BEC absorbs them. Measured

R18/R19 set the switchover threshold at VREF * 133/33 = 4.03 V on VIN1
(VREF = 0.92 to 1.08 V, so 3.7 to 4.35 V worst case; the buck holds 5 V +/-2 %, so no parasitic switchover). With VIN1 dead (bench, USB only) MODE is low and PR1 is low, and the truth

passive part can hold 5.25 V and cap at 6 V - only an active OVP switch could, and a compliant UFP source never leaves 5 V. See PWR-3. The divider now hangs on the raw battery instead of a
regulated rail, so pack voltage is directly visible; the old
input-rail divider could not see it. R1/R2 = 100k/12k, ratio 12/112 = 0.10714. Tap = 2.70 V at 25.2 V (6S max), 1.80 V at 16.8 V (4S max), and 3.3 V (VDDA) is reached only at 30.8 V, so any plausible

table passes the higher of the two inputs: the board runs on USB with
nothing to command. Switchover is BREAK-before-make, tSW = 8 us at 5 V: C5 + C26 keep the droop

near 145 mV at 400 mA. VIN abs max is 6 V (5.5 V recommended). Unlike the Schottky stage, this node

pack transient stays inside the ADC range. Drain 0.22 mA continuous while the pack is plugged; source

is no longer indifferent to a USB overvoltage. No extra TVS was added for
that (2026-08-17): U7 (USBLC6-2SC6) already clamps VBUS at VBR 6.1 V, and no

impedance 10.7 k, fine because C7 sits at the pin and the
conversion runs at about 1 Hz with a long sampling time. D3 clamps negative excursions: DS11853 Table 60 allows

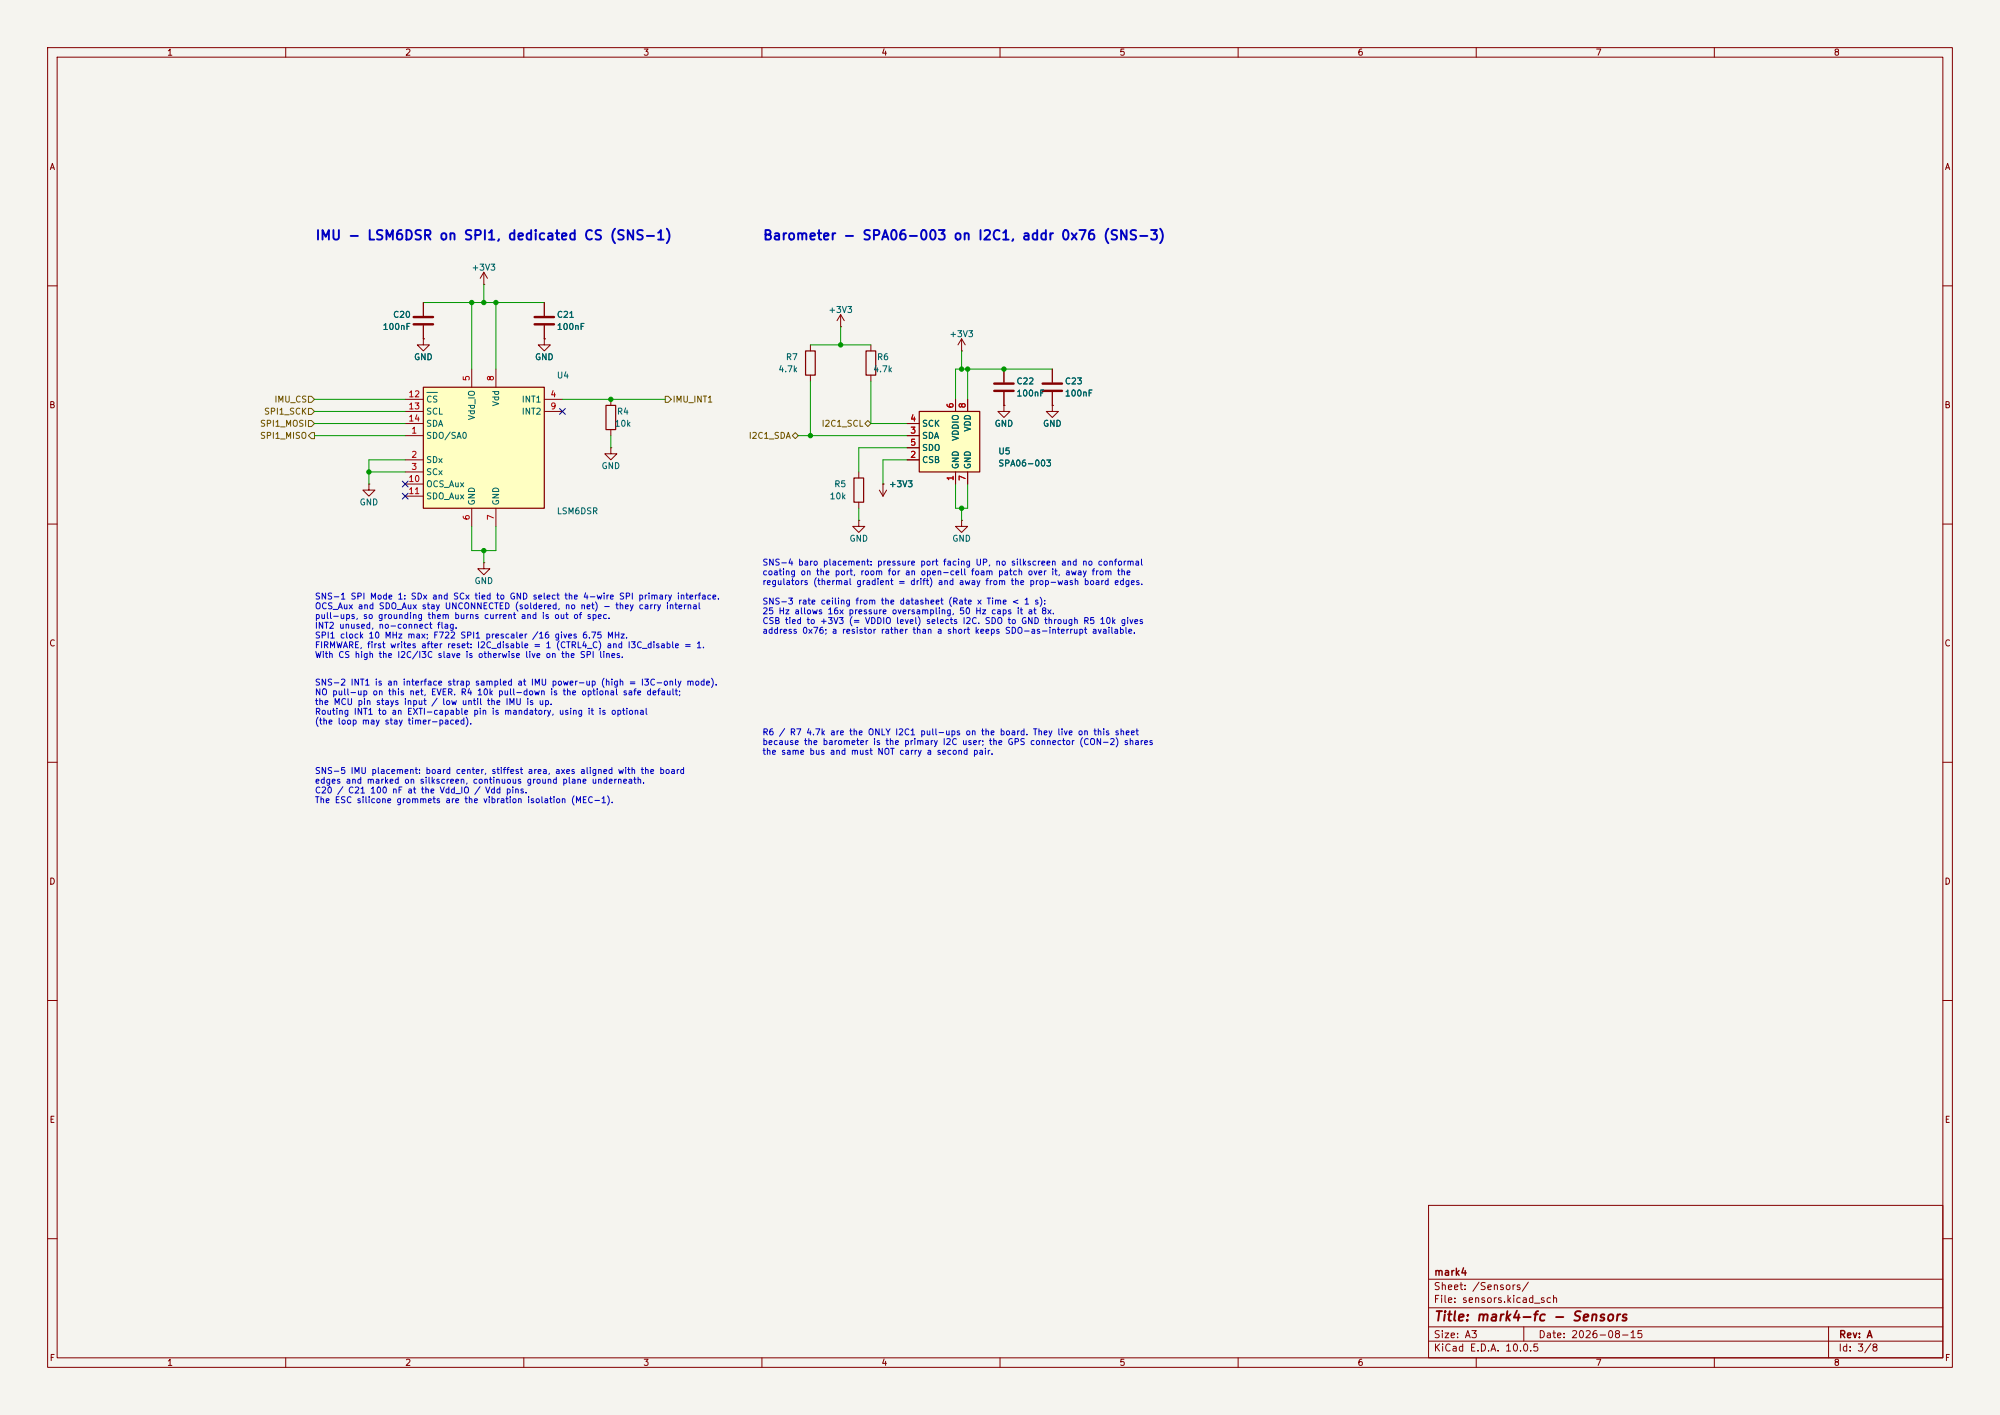
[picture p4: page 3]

IMU - LSM6DSR on SPI1, dedicated CS (SNS-1)

Barometer - SPA06-003 on I2C1, addr 0x76 (SNS-3)

I2C1_SCL SNS-2 INT1 is an interface strap sampled at IMU power-up (high = I3C-only mode). NO pull-up on this net, EVER. R4 10k pull-down is the optional safe default; the MCU pin stays input / low until the IMU is up. Routing INT1 to an EXTI-capable pin is mandatory, using it is optional

the same bus and must NOT carry a second pair. SNS-4 baro placement: pressure port facing UP, no silkscreen and no conformal coating on the port, room for an open-cell foam patch over it, away from the

(the loop may stay timer-paced). SNS-1 SPI Mode 1: SDx and SCx tied to GND select the 4-wire SPI primary interface. OCS_Aux and SDO_Aux stay UNCONNECTED (soldered, no net) - they carry internal pull-ups, so grounding them burns current and is out of spec.

INT2 unused, no-connect flag. SPI1 clock 10 MHz max; F722 SPI1 prescaler /16 gives 6.75 MHz. FIRMWARE, first writes after reset: I2C_disable = 1 (CTRL4_C) and I3C_disable = 1. With CS high the I2C/I3C slave is otherwise live on the SPI lines.

R6 / R7 4.7k are the ONLY I2C1 pull-ups on the board. They live on this sheet because the barometer is the primary I2C user; the GPS connector (CON-2) shares

SNS-5 IMU placement: board center, stiffest area, axes aligned with the board
edges and marked on silkscreen, continuous ground plane underneath. C20 / C21 100 nF at the Vdd_IO / Vdd pins. The ESC silicone grommets are the vibration isolation (MEC-1).

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
## Title: mark4-fc - Storage

### File: storage.kicad_sch

### Sheet: /Storage/

mark4

GND

R8

10k R10

10k | R9
10k | GND

C24
100nF CS 1 | DO/IO1 2 | WP/IO2 3 | GND

4 DI/IO0 5 CLK 6 HOLD/RESET/IO3 7 VCC

8 U6 W25Q128JVSIQ +3V3

SPI2_MOSI SPI2_SCK

SPI2_MISO
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

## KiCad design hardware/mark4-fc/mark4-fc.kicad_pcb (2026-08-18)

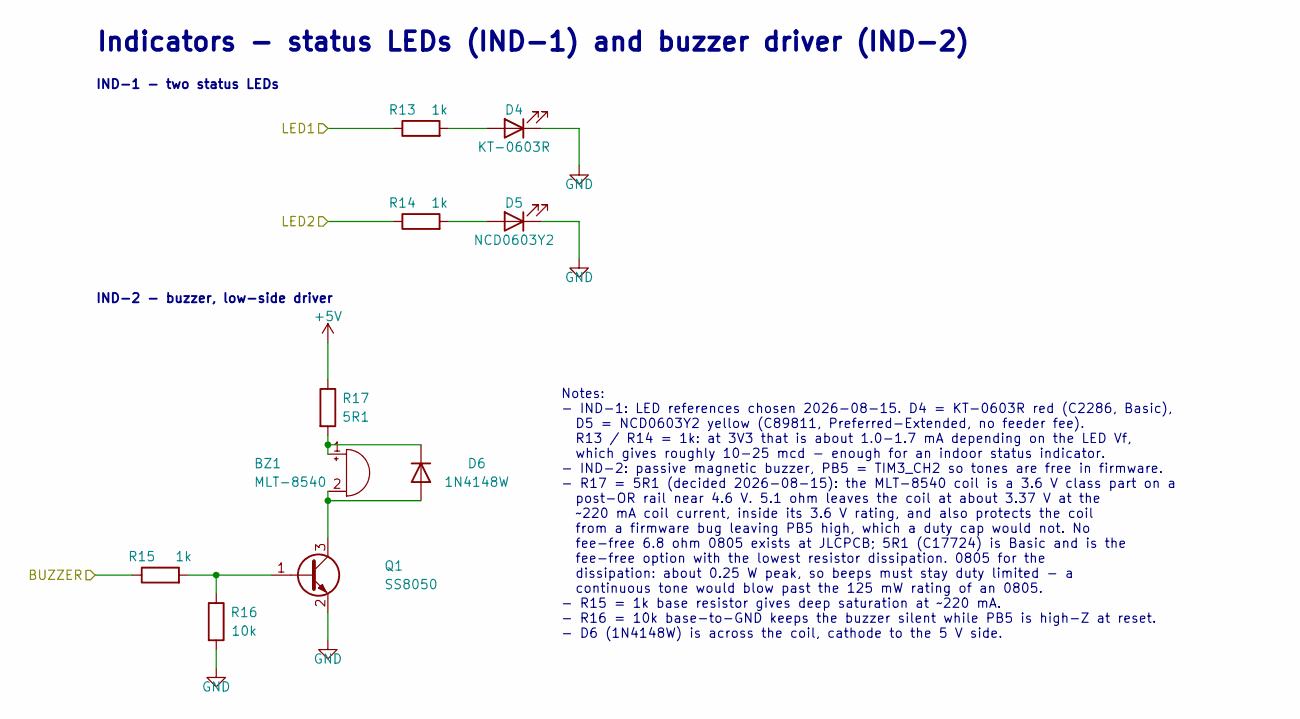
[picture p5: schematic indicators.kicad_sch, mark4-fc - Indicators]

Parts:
BZ1: MLT-8540; Buzzer_MLT-8540; MPN MLT-8540; LCSC C95300
D4: KT-0603R; LED_0603_1608Metric; MPN KT-0603R; LCSC C2286
D5: NCD0603Y2; LED_0603_1608Metric; MPN NCD0603Y2; LCSC C89811
D6: 1N4148W; D_SOD-123; MPN 1N4148W; LCSC C81598
Q1: SS8050; SOT-23; MPN S8050; LCSC C2146
R13, R14, R15: 1k; R_0603_1608Metric; MPN 0603WAF1001T5E; LCSC C21190
R16: 10k; R_0603_1608Metric; MPN 0603WAF1002T5E; LCSC C25804
R17: 5R1; R_0805_2012Metric; MPN 0805W8F510KT5E; LCSC C17724

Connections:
+5V: R17.1; also elsewhere on the board
/BUZZER: R15.1; also elsewhere on the board
/LED1: R13.1; also elsewhere on the board
/LED2: R14.1; also elsewhere on the board
GND: D4.1 (K), D5.1 (K), Q1.2 (E), R16.2; also elsewhere on the board
unnamed: BZ1.1 (+), D6.1 (K), R17.2
unnamed: BZ1.2 (-), D6.2 (A), Q1.3 (C)
unnamed: D4.2 (A), R13.2
unnamed: D5.2 (A), R14.2
unnamed: Q1.1 (B), R15.2, R16.1

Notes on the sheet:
IND-2 - buzzer, low-side driver
Notes: - IND-1: LED references chosen 2026-08-15. D4 = KT-0603R red (C2286, Basic), D5 = NCD0603Y2 yellow (C89811, Preferred-Extended, no feeder fee). R13 / R14 = 1k: at 3V3 that is about 1.0-1.7 mA depending on the LED Vf, which gives roughly 10-25 mcd - enough for an indoor status indicator. - IN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
Indicators - status LEDs (IND-1) and buzzer driver (IND-2)
IND-1 - two status LEDs

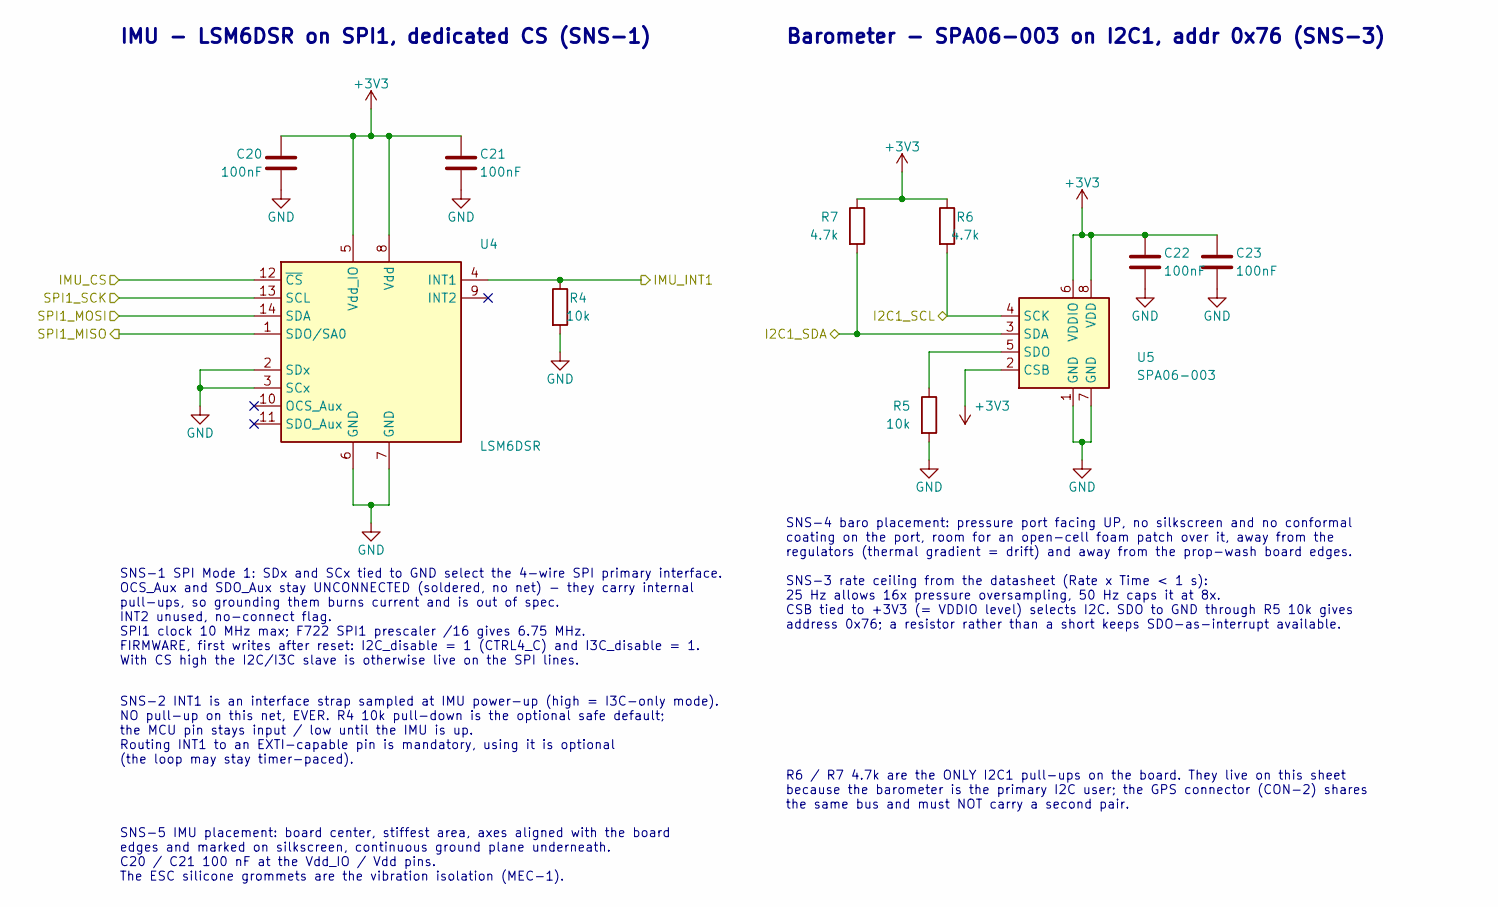
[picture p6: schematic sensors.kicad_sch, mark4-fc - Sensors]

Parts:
C20, C21, C22, C23: 100nF; C_0603_1608Metric; MPN CC0603KRX7R9BB104; LCSC C14663
R4, R5: 10k; R_0603_1608Metric; MPN 0603WAF1002T5E; LCSC C25804
R6, R7: 4.7k; R_0603_1608Metric; MPN 0603WAF4701T5E; LCSC C23162
U4: LSM6DSR; LGA-14_3x2.5mm_P0.5mm_LayoutBorder3x4y; MPN LSM6DSRTR; LCSC C784817
U5: SPA06-003; Goertek_LGA-8_2x2.5mm_P0.65mm_ClockwisePinNumbering; MPN SPA06-003; LCSC C30589048

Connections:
+3V3: C20.1, C21.1, C22.1, C23.1, R6.1, R7.1, U4.5 (Vdd_IO), U4.8 (Vdd), U5.2 (CSB), U5.6 (VDDIO), U5.8 (VDD); also elsewhere on the board
/I2C1_SCL: R6.2, U5.4 (SCK); also elsewhere on the board
/I2C1_SDA: R7.2, U5.3 (SDA); also elsewhere on the board
/IMU_CS: U4.12 (~CS); also elsewhere on the board
/IMU_INT1: R4.1, U4.4 (INT1); also elsewhere on the board
/SPI1_MISO: U4.1 (SDO/SA0); also elsewhere on the board
/SPI1_MOSI: U4.14 (SDA); also elsewhere on the board
/SPI1_SCK: U4.13 (SCL); also elsewhere on the board
GND: C20.2, C21.2, C22.2, C23.2, R4.2, R5.2, U4.2 (SDx), U4.3 (SCx), U4.6 (GND), U4.7 (GND), U5.1 (GND), U5.7 (GND); also elsewhere on the board
unnamed: R5.1, U5.5 (SDO)

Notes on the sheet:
SNS-5 IMU placement: board center, stiffest area, axes aligned with the board edges and marked on silkscreen, continuous ground plane underneath. C20 / C21 100 nF at the Vdd_IO / Vdd pins. The ESC silicone grommets are the vibration isolation (MEC-1).
SNS-4 baro placement: pressure port facing UP, no silkscreen and no conformal coating on the port, room for an open-cell foam patch over it, away from the regulators (thermal gradient = drift) and away from the prop-wash board edges. SNS-3 rate ceiling from the datasheet (Rate x Time < 1 s): 25 Hz 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
Barometer - SPA06-003 on I2C1, addr 0x76 (SNS-3)
SNS-1 SPI Mode 1: SDx and SCx tied to GND select the 4-wire SPI primary interface. OCS_Aux and SDO_Aux stay UNCONNECTED (soldered, no net) - they carry internal pull-ups, so grounding them burns current and is out of spec. INT2 unused, no-connect flag. SPI1 clock 10 MHz max; F722 SPI1 prescaler /16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
IMU - LSM6DSR on SPI1, dedicated CS (SNS-1)
SNS-2 INT1 is an interface strap sampled at IMU power-up (high = I3C-only mode). NO pull-up on this net, EVER. R4 10k pull-down is the optional safe default; the MCU pin stays input / low until the IMU is up. Routing INT1 to an EXTI-capable pin is mandatory, using it is optional (the loop may stay 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
R6 / R7 4.7k are the ONLY I2C1 pull-ups on the board. They live on this sheet because the barometer is the primary I2C user; the GPS connector (CON-2) shares the same bus and must NOT carry a second pair.

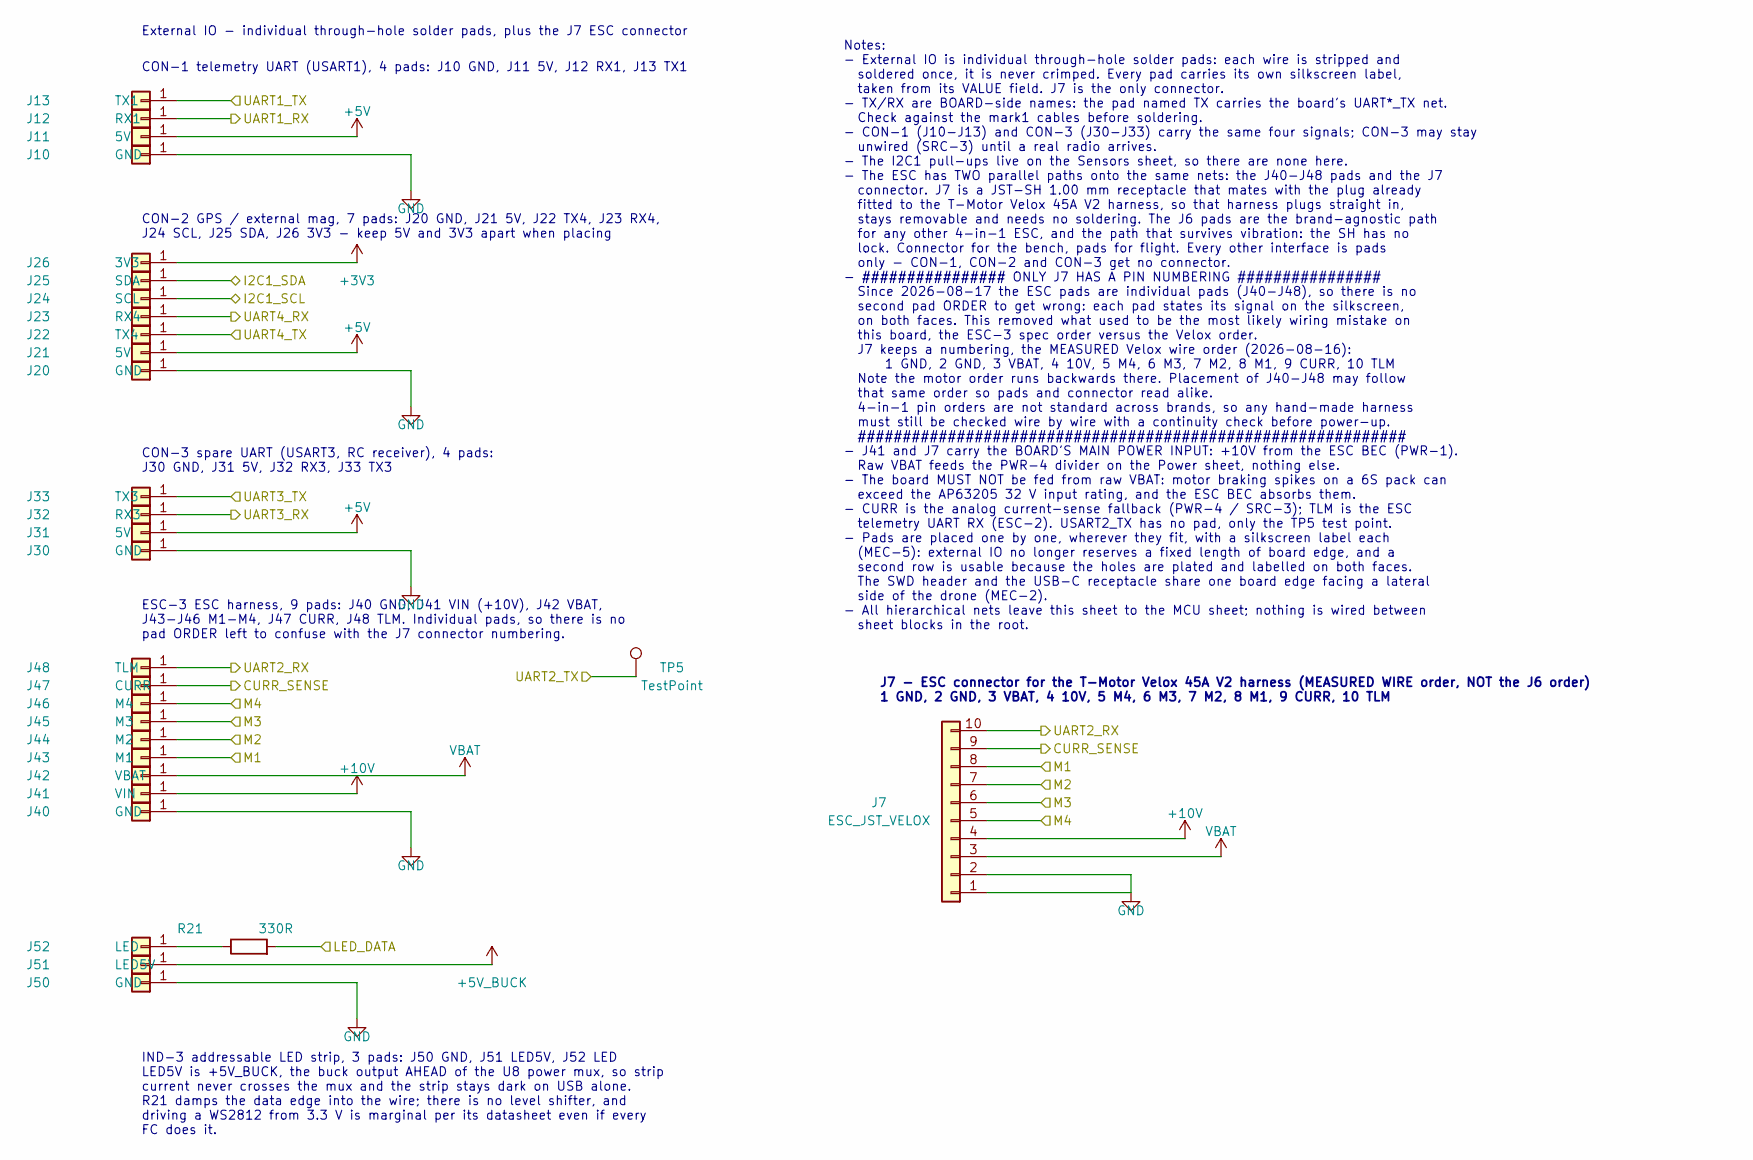
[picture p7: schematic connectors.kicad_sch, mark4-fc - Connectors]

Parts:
J7: ESC_JST_VELOX; JST_SH_SM10B-SRSS-TB_1x10-1MP_P1.00mm_Horizontal; MPN SM10B-SRSS-TB(LF)(SN); LCSC C160409
J10, J20, J30, J40, J50: GND; SolderPad_1x01_THT
J11, J21, J31: 5V; SolderPad_1x01_THT
J12: RX1; SolderPad_1x01_THT
J13: TX1; SolderPad_1x01_THT
J22: TX4; SolderPad_1x01_THT
J23: RX4; SolderPad_1x01_THT
J24: SCL; SolderPad_1x01_THT
J25: SDA; SolderPad_1x01_THT
J26: 3V3; SolderPad_1x01_THT
J32: RX3; SolderPad_1x01_THT
J33: TX3; SolderPad_1x01_THT
J41: VIN; SolderPad_1x01_THT
J42: VBAT; SolderPad_1x01_THT
J43: M1; SolderPad_1x01_THT
J44: M2; SolderPad_1x01_THT
J45: M3; SolderPad_1x01_THT
J46: M4; SolderPad_1x01_THT
J47: CURR; SolderPad_1x01_THT
J48: TLM; SolderPad_1x01_THT
J51: LED5V; SolderPad_1x01_THT
J52: LED; SolderPad_1x01_THT
R21: 330R; R_0603_1608Metric; MPN 0603WAF3300T5E; LCSC C23138
TP5: TestPoint; TestPoint_Pad_D1.5mm

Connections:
+3V3: J26.1; also elsewhere on the board
+5V: J11.1, J21.1, J31.1; also elsewhere on the board
+5V_BUCK: J51.1; also elsewhere on the board
+10V: J7.4, J41.1; also elsewhere on the board
/CURR_SENSE: J7.9, J47.1; also elsewhere on the board
/I2C1_SCL: J24.1; also elsewhere on the board
/I2C1_SDA: J25.1; also elsewhere on the board
/LED_DATA: R21.2; also elsewhere on the board
/M1: J7.8, J43.1; also elsewhere on the board
/M2: J7.7, J44.1; also elsewhere on the board
/M3: J7.6, J45.1; also elsewhere on the board
/M4: J7.5, J46.1; also elsewhere on the board
/UART1_RX: J12.1; also elsewhere on the board
/UART1_TX: J13.1; also elsewhere on the board
/UART2_RX: J7.10, J48.1; also elsewhere on the board
/UART2_TX: TP5.1; also elsewhere on the board
/UART3_RX: J32.1; also elsewhere on the board
/UART3_TX: J33.1; also elsewhere on the board
/UART4_RX: J23.1; also elsewhere on the board
/UART4_TX: J22.1; also elsewhere on the board
GND: J7.1, J7.2, J10.1, J20.1, J30.1, J40.1, J50.1; also elsewhere on the board
unnamed: J52.1, R21.1
VBAT: J7.3, J42.1; also elsewhere on the board

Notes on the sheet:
Notes: - External IO is individual through-hole solder pads: each wire is stripped and soldered once, it is never crimped. Every pad carries its own silkscreen label, taken from its VALUE field. J7 is the only connector. - TX/RX are BOARD-side names: the pad named TX carries the board's UART*_TX ne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
J7 - ESC connector for the T-Motor Velox 45A V2 harness (MEASURED WIRE order, NOT the J6 order) 1 GND, 2 GND, 3 VBAT, 4 10V, 5 M4, 6 M3, 7 M2, 8 M1, 9 CURR, 10 TLM
CON-1 telemetry UART (USART1), 4 pads: J10 GND, J11 5V, J12 RX1, J13 TX1
CON-2 GPS / external mag, 7 pads: J20 GND, J21 5V, J22 TX4, J23 RX4, J24 SCL, J25 SDA, J26 3V3 - keep 5V and 3V3 apart when placing
CON-3 spare UART (USART3, RC receiver), 4 pads: J30 GND, J31 5V, J32 RX3, J33 TX3
ESC-3 ESC harness, 9 pads: J40 GND, J41 VIN (+10V), J42 VBAT, J43-J46 M1-M4, J47 CURR, J48 TLM. Individual pads, so there is no pad ORDER left to confuse with the J7 connector numbering.
IND-3 addressable LED strip, 3 pads: J50 GND, J51 LED5V, J52 LED LED5V is +5V_BUCK, the buck output AHEAD of the U8 power mux, so strip current never crosses the mux and the strip stays dark on USB alone. R21 damps the data edge into the wire; there is no level shifter, and driving a WS2812 from 3.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
External IO - individual through-hole solder pads, plus the J7 ESC connector

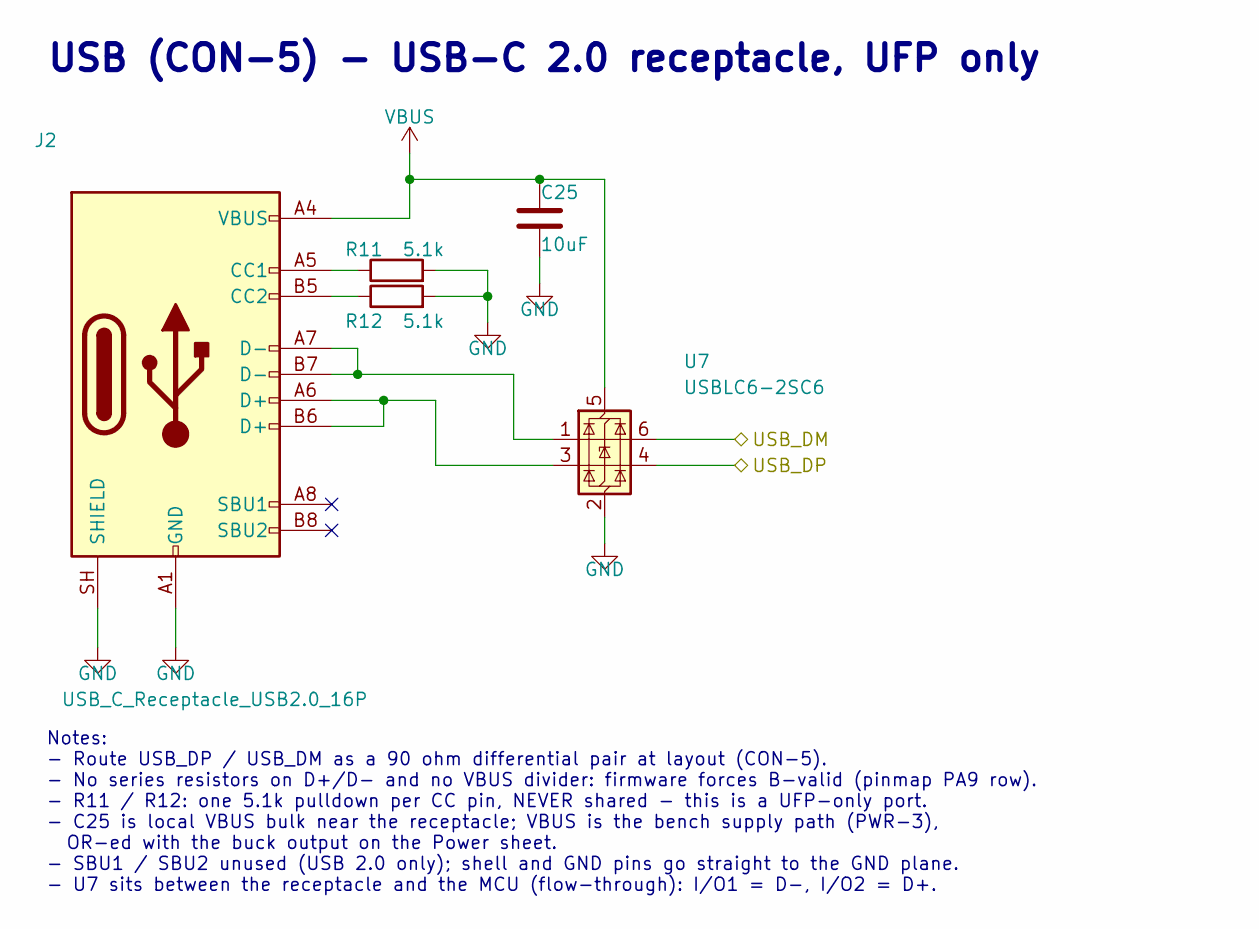
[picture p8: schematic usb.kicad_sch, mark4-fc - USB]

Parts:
C25: 10uF; C_0805_2012Metric; MPN CL21A106KAYNNNE; LCSC C15850
J2: USB_C_Receptacle_USB2.0_16P; USB_C_Receptacle_HRO_TYPE-C-31-M-12; MPN TYPE-C-31-M-12; LCSC C165948
R11, R12: 5.1k; R_0603_1608Metric; MPN 0603WAF5101T5E; LCSC C23186
U7: USBLC6-2SC6; SOT-23-6; MPN USBLC6-2SC6; LCSC C7519

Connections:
/USB_DM: U7.6 (I/O1); also elsewhere on the board
/USB_DP: U7.4 (I/O2); also elsewhere on the board
GND: C25.2, J2.A1 (GND), J2.A12 (GND), J2.B1 (GND), J2.B12 (GND), J2.SH (SHIELD), R11.2, R12.2, U7.2 (GND); also elsewhere on the board
unnamed: J2.A5 (CC1), R11.1
unnamed: J2.B5 (CC2), R12.1
unnamed: J2.A6 (D+), J2.B6 (D+), U7.3 (I/O2)
unnamed: J2.A7 (D-), J2.B7 (D-), U7.1 (I/O1)
VBUS: C25.1, J2.A4 (VBUS), J2.A9 (VBUS), J2.B4 (VBUS), J2.B9 (VBUS), U7.5 (VBUS); also elsewhere on the board

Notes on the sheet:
USB (CON-5) - USB-C 2.0 receptacle, UFP only
Notes: - Route USB_DP / USB_DM as a 90 ohm differential pair at layout (CON-5). - No series resistors on D+/D- and no VBUS divider: firmware forces B-valid (pinmap PA9 row). - R11 / R12: one 5.1k pulldown per CC pin, NEVER shared - this is a UFP-only port. - C25 is local VBUS bulk near the receptac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

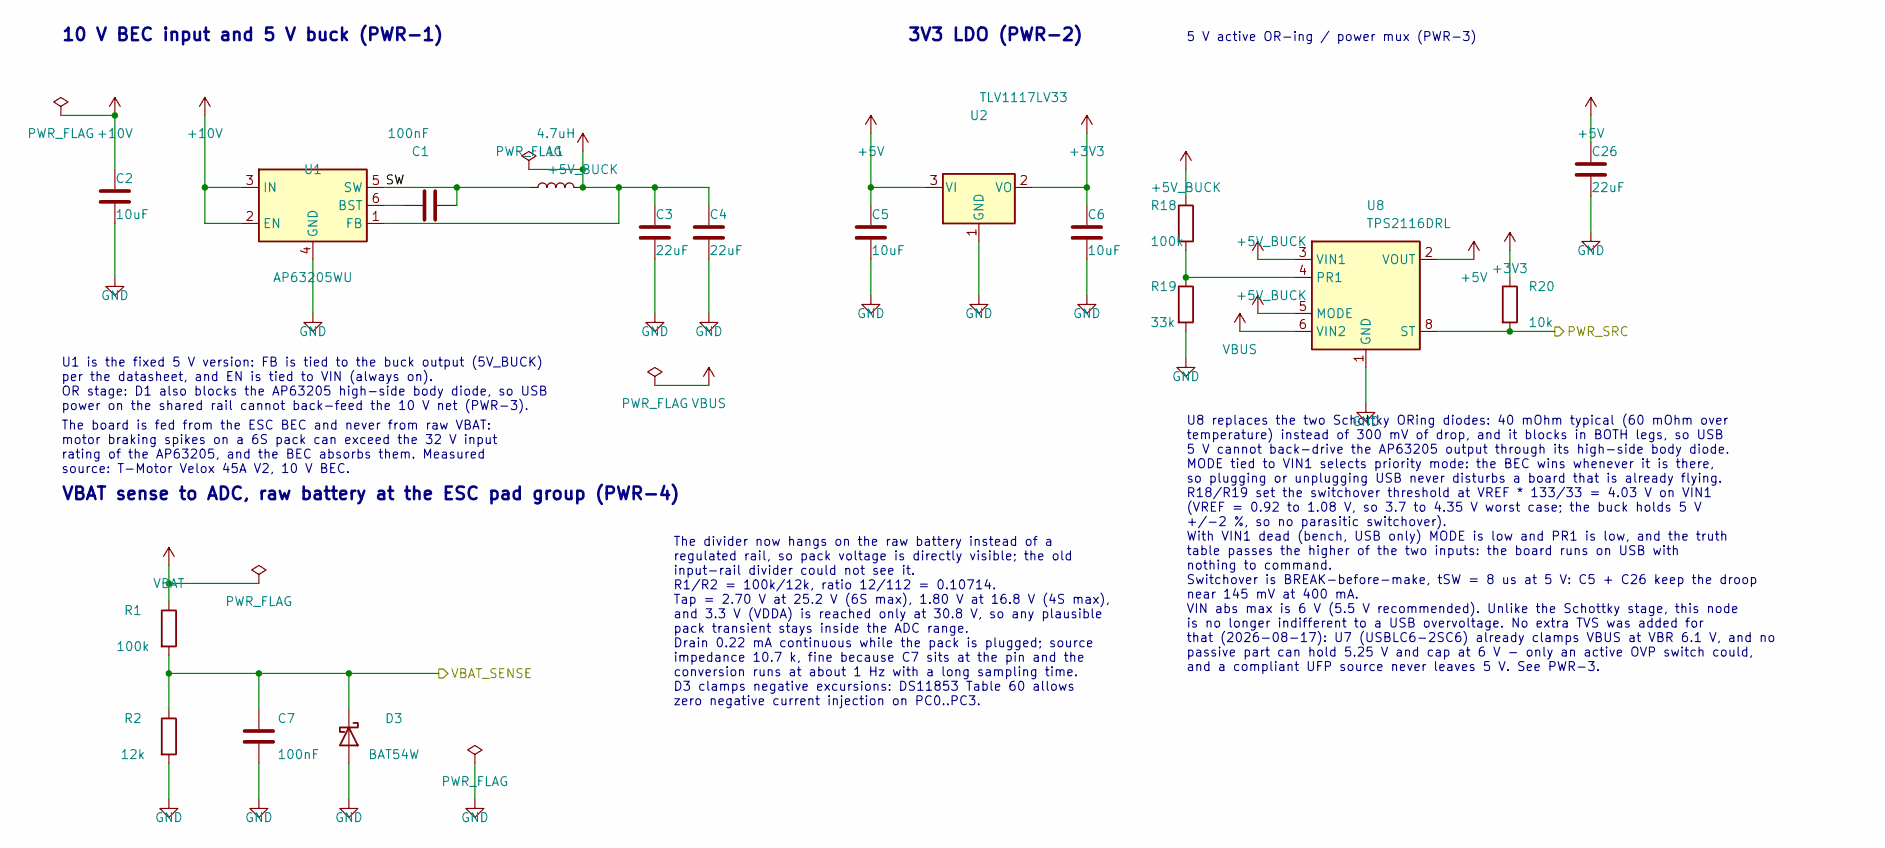
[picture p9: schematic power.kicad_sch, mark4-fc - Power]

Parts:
C1, C7: 100nF; C_0603_1608Metric; MPN CC0603KRX7R9BB104; LCSC C14663
C2, C5, C6: 10uF; C_0805_2012Metric; MPN CL21A106KAYNNNE; LCSC C15850
C3, C4, C26: 22uF; C_0805_2012Metric; MPN CL21A226MAQNNNE; LCSC C45783
D3: BAT54W; D_SOD-123; MPN BAT54W; LCSC C7502705
L1: 4.7uH; L_Sunlord_SWPA5040S; MPN SWPA5040S4R7MT; LCSC C48496
R1, R18: 100k; R_0603_1608Metric; MPN 0603WAF1003T5E; LCSC C25803
R2: 12k; R_0603_1608Metric; MPN 0603WAF1202T5E; LCSC C22790
R19: 33k; R_0603_1608Metric; MPN 0603WAF3302T5E; LCSC C4216
R20: 10k; R_0603_1608Metric; MPN 0603WAF1002T5E; LCSC C25804
U1: AP63205WU; TSOT-23-6; MPN AP63205WU-7; LCSC C2071056
U2: TLV1117LV33; SOT-223-3_TabPin2; MPN TLV1117LV33DCYR; LCSC C15578
U8: TPS2116DRL; SOT-583-8; MPN TPS2116DRLR; LCSC C3235557

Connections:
+3V3: C6.1, R20.1, U2.2 (VO); also elsewhere on the board
+5V: C5.1, C26.1, U2.3 (VI), U8.2 (VOUT), U8.7 (VOUT); also elsewhere on the board
+5V_BUCK: C3.1, C4.1, L1.2, R18.1, U1.1 (FB), U8.3 (VIN1), U8.5 (MODE); also elsewhere on the board
+10V: C2.1, U1.2 (EN), U1.3 (IN); also elsewhere on the board
/PWR_SRC: R20.2, U8.8 (ST); also elsewhere on the board
/Power/SW: C1.2, L1.1, U1.5 (SW)
/VBAT_SENSE: C7.1, D3.1 (K), R1.2, R2.1; also elsewhere on the board
GND: C2.2, C3.2, C4.2, C5.2, C6.2, C7.2, C26.2, D3.2 (A), R2.2, R19.2, U1.4 (GND), U2.1 (GND), U8.1 (GND); also elsewhere on the board
unnamed: C1.1, U1.6 (BST)
unnamed: R18.2, R19.1, U8.4 (PR1)
VBAT: R1.1; also elsewhere on the board
VBUS: U8.6 (VIN2); also elsewhere on the board

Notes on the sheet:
The board is fed from the ESC BEC and never from raw VBAT: motor braking spikes on a 6S pack can exceed the 32 V input rating of the AP63205, and the BEC absorbs them. Measured source: T-Motor Velox 45A V2, 10 V BEC.
The divider now hangs on the raw battery instead of a regulated rail, so pack voltage is directly visible; the old input-rail divider could not see it. R1/R2 = 100k/12k, ratio 12/112 = 0.10714. Tap = 2.70 V at 25.2 V (6S max), 1.80 V at 16.8 V (4S max), and 3.3 V (VDDA) is reached only at 30.8 V, s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
3V3 LDO (PWR-2)
VBAT sense to ADC, raw battery at the ESC pad group (PWR-4)
5 V active OR-ing / power mux (PWR-3)
U8 replaces the two Schottky ORing diodes: 40 mOhm typical (60 mOhm over temperature) instead of 300 mV of drop, and it blocks in BOTH legs, so USB 5 V cannot back-drive the AP63205 output through its high-side body diode. MODE tied to VIN1 selects priority mode: the BEC wins whenever it is there, 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
U1 is the fixed 5 V version: FB is tied to the buck output (5V_BUCK) per the datasheet, and EN is tied to VIN (always on). OR stage: D1 also blocks the AP63205 high-side body diode, so USB power on the shared rail cannot back-feed the 10 V net (PWR-3).
10 V BEC input and 5 V buck (PWR-1)

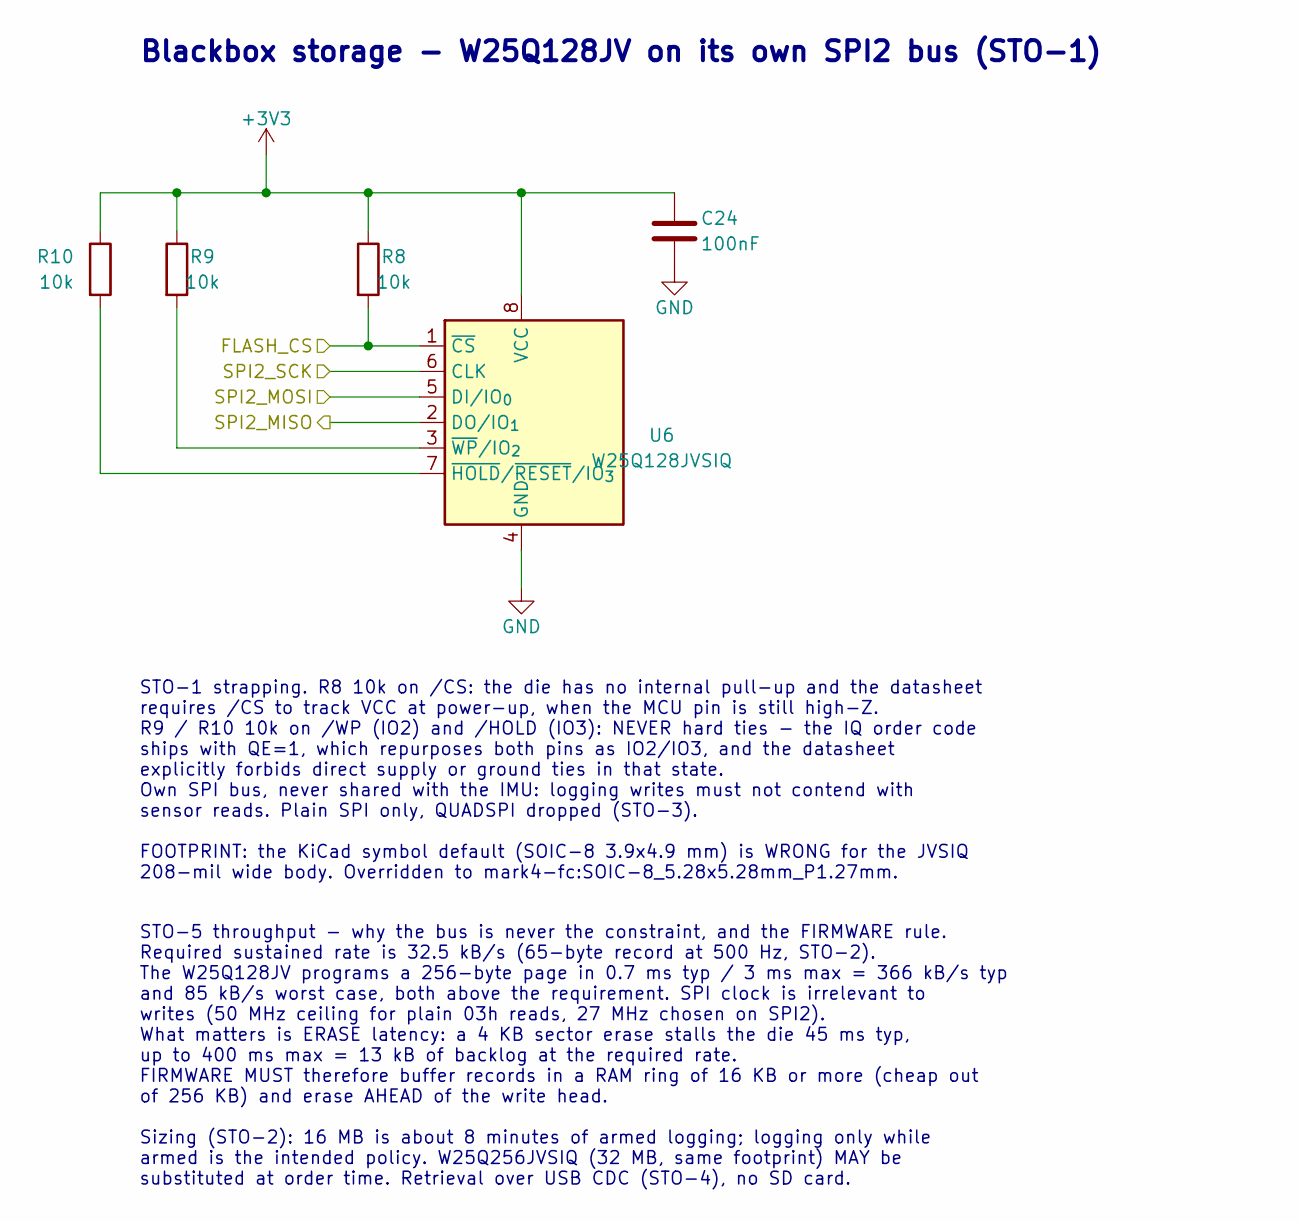
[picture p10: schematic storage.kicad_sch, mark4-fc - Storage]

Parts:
C24: 100nF; C_0603_1608Metric; MPN CC0603KRX7R9BB104; LCSC C14663
R8, R9, R10: 10k; R_0603_1608Metric; MPN 0603WAF1002T5E; LCSC C25804
U6: W25Q128JVSIQ; SOIC-8_5.28x5.28mm_P1.27mm; MPN W25Q128JVSIQ; LCSC C97521

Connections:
+3V3: C24.1, R8.1, R9.1, R10.1, U6.8 (VCC); also elsewhere on the board
/FLASH_CS: R8.2, U6.1 (~CS); also elsewhere on the board
/SPI2_MISO: U6.2 (DO/IO_{1}); also elsewhere on the board
/SPI2_MOSI: U6.5 (DI/IO_{0}); also elsewhere on the board
/SPI2_SCK: U6.6 (CLK); also elsewhere on the board
GND: C24.2, U6.4 (GND); also elsewhere on the board
unnamed: R10.2, U6.7 (~HOLD/~RESET/IO_{3})
unnamed: R9.2, U6.3 (~WP/IO_{2})

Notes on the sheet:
Blackbox storage - W25Q128JV on its own SPI2 bus (STO-1)
STO-1 strapping. R8 10k on /CS: the die has no internal pull-up and the datasheet requires /CS to track VCC at power-up, when the MCU pin is still high-Z. R9 / R10 10k on /WP (IO2) and /HOLD (IO3): NEVER hard ties - the IQ order code ships with QE=1, which repurposes both pins as IO2/IO3, and the d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
STO-5 throughput - why the bus is never the constraint, and the FIRMWARE rule. Required sustained rate is 32.5 kB/s (65-byte record at 500 Hz, STO-2). The W25Q128JV programs a 256-byte page in 0.7 ms typ / 3 ms max = 366 kB/s typ and 85 kB/s worst case, both above the requirement. SPI clock is irre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

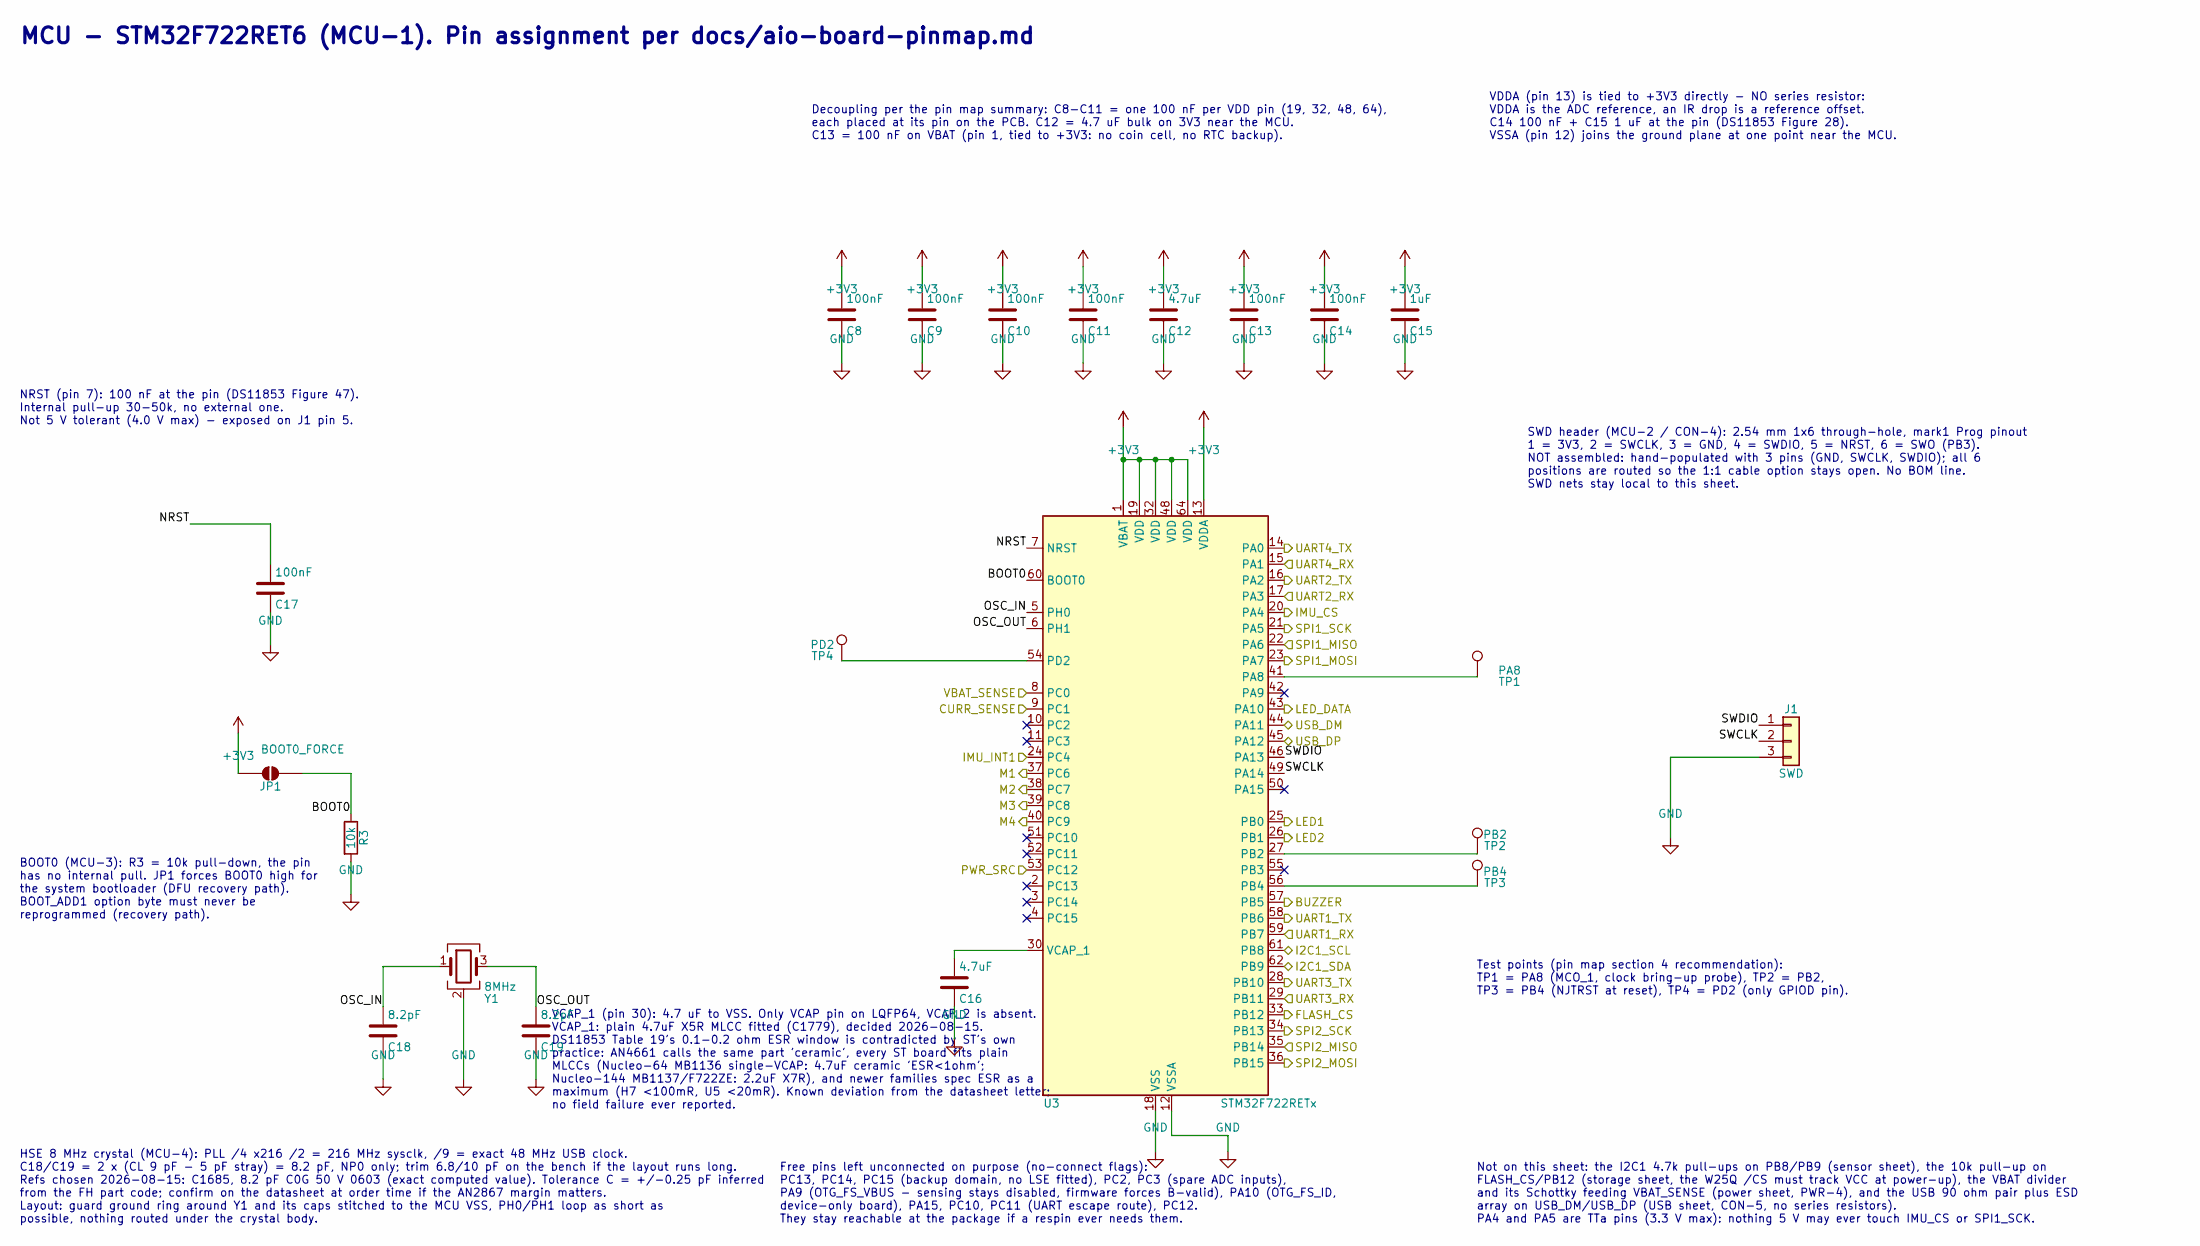
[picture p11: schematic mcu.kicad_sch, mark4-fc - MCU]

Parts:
C8, C9, C10, C11, C13, C14, C17: 100nF; C_0603_1608Metric; MPN CC0603KRX7R9BB104; LCSC C14663
C12, C16: 4.7uF; C_0805_2012Metric; MPN CL21A475KAQNNNE; LCSC C1779
C15: 1uF; C_0603_1608Metric; MPN CL10A105KB8NNNC; LCSC C15849
C18, C19: 8.2pF; C_0603_1608Metric; MPN 0603CG8R2C500NT; LCSC C1685
J1: SWD; PinHeader_1x03_P2.54mm_Vertical
JP1: BOOT0_FORCE; SolderJumper-2_P1.3mm_Open_TrianglePad1.0x1.5mm
R3: 10k; R_0603_1608Metric; MPN 0603WAF1002T5E; LCSC C25804
TP1: PA8; TestPoint_Pad_D1.5mm
TP2: PB2; TestPoint_Pad_D1.5mm
TP3: PB4; TestPoint_Pad_D1.5mm
TP4: PD2; TestPoint_Pad_D1.5mm
U3: STM32F722RETx; LQFP-64_10x10mm_P0.5mm; MPN STM32F722RET6; LCSC C118207
Y1: 8MHz; Crystal_SMD_3225-4Pin_3.2x2.5mm; MPN CJ13-080000910B20; LCSC C712812

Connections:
+3V3: C8.1, C9.1, C10.1, C11.1, C12.1, C13.1, C14.1, C15.1, JP1.1 (A), U3.1 (VBAT), U3.13 (VDDA), U3.19 (VDD), U3.32 (VDD), U3.48 (VDD), U3.64 (VDD); also elsewhere on the board
/BUZZER: U3.57 (PB5); also elsewhere on the board
/CURR_SENSE: U3.9 (PC1); also elsewhere on the board
/FLASH_CS: U3.33 (PB12); also elsewhere on the board
/I2C1_SCL: U3.61 (PB8); also elsewhere on the board
/I2C1_SDA: U3.62 (PB9); also elsewhere on the board
/IMU_CS: U3.20 (PA4); also elsewhere on the board
/IMU_INT1: U3.24 (PC4); also elsewhere on the board
/LED1: U3.25 (PB0); also elsewhere on the board
/LED2: U3.26 (PB1); also elsewhere on the board
/LED_DATA: U3.43 (PA10); also elsewhere on the board
/M1: U3.37 (PC6); also elsewhere on the board
/M2: U3.38 (PC7); also elsewhere on the board
/M3: U3.39 (PC8); also elsewhere on the board
/M4: U3.40 (PC9); also elsewhere on the board
/MCU/BOOT0: JP1.2 (B), R3.1, U3.60 (BOOT0)
/MCU/NRST: C17.1, U3.7 (NRST)
/MCU/OSC_IN: C18.1, U3.5 (PH0), Y1.1
/MCU/OSC_OUT: C19.1, U3.6 (PH1), Y1.3
/MCU/SWCLK: J1.2, U3.49 (PA14)
/MCU/SWDIO: J1.1, U3.46 (PA13)
/MCU/SWO: U3.55 (PB3)
/PWR_SRC: U3.53 (PC12); also elsewhere on the board
/SPI1_MISO: U3.22 (PA6); also elsewhere on the board
/SPI1_MOSI: U3.23 (PA7); also elsewhere on the board
/SPI1_SCK: U3.21 (PA5); also elsewhere on the board
/SPI2_MISO: U3.35 (PB14); also elsewhere on the board
/SPI2_MOSI: U3.36 (PB15); also elsewhere on the board
/SPI2_SCK: U3.34 (PB13); also elsewhere on the board
/UART1_RX: U3.59 (PB7); also elsewhere on the board
/UART1_TX: U3.58 (PB6); also elsewhere on the board
/UART2_RX: U3.17 (PA3); also elsewhere on the board
/UART2_TX: U3.16 (PA2); also elsewhere on the board
/UART3_RX: U3.29 (PB11); also elsewhere on the board
/UART3_TX: U3.28 (PB10); also elsewhere on the board
/UART4_RX: U3.15 (PA1); also elsewhere on the board
/UART4_TX: U3.14 (PA0); also elsewhere on the board
/USB_DM: U3.44 (PA11); also elsewhere on the board
/USB_DP: U3.45 (PA12); also elsewhere on the board
/VBAT_SENSE: U3.8 (PC0); also elsewhere on the board
GND: C8.2, C9.2, C10.2, C11.2, C12.2, C13.2, C14.2, C15.2, C16.2, C17.2, C18.2, C19.2, J1.3, R3.2, U3.12 (VSSA), U3.18 (VSS), U3.31 (VSS), U3.47 (VSS), U3.63 (VSS), Y1.2 (G), Y1.4 (G); also elsewhere on the board
unnamed: TP1.1, U3.41 (PA8)
unnamed: TP2.1, U3.27 (PB2)
unnamed: TP3.1, U3.56 (PB4)
unnamed: TP4.1, U3.54 (PD2)
unnamed: C16.1, U3.30 (VCAP_1)

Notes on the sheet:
Test points (pin map section 4 recommendation): TP1 = PA8 (MCO_1, clock bring-up probe), TP2 = PB2, TP3 = PB4 (NJTRST at reset), TP4 = PD2 (only GPIOD pin).
HSE 8 MHz crystal (MCU-4): PLL /4 x216 /2 = 216 MHz sysclk, /9 = exact 48 MHz USB clock. C18/C19 = 2 x (CL 9 pF - 5 pF stray) = 8.2 pF, NP0 only; trim 6.8/10 pF on the bench if the layout runs long. Refs chosen 2026-08-15: C1685, 8.2 pF C0G 50 V 0603 (exact computed value). Tolerance C = +/-0.25 pF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
SWD header (MCU-2 / CON-4): 2.54 mm 1x6 through-hole, mark1 Prog pinout 1 = 3V3, 2 = SWCLK, 3 = GND, 4 = SWDIO, 5 = NRST, 6 = SWO (PB3). NOT assembled: hand-populated with 3 pins (GND, SWCLK, SWDIO); all 6 positions are routed so the 1:1 cable option stays open. No BOM line. SWD nets stay local to 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
BOOT0 (MCU-3): R3 = 10k pull-down, the pin has no internal pull. JP1 forces BOOT0 high for the system bootloader (DFU recovery path). BOOT_ADD1 option byte must never be reprogrammed (recovery path).
Not on this sheet: the I2C1 4.7k pull-ups on PB8/PB9 (sensor sheet), the 10k pull-up on FLASH_CS/PB12 (storage sheet, the W25Q /CS must track VCC at power-up), the VBAT divider and its Schottky feeding VBAT_SENSE (power sheet, PWR-4), and the USB 90 ohm pair plus ESD array on USB_DM/USB_DP (USB she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
Free pins left unconnected on purpose (no-connect flags): PC13, PC14, PC15 (backup domain, no LSE fitted), PC2, PC3 (spare ADC inputs), PA9 (OTG_FS_VBUS - sensing stays disabled, firmware forces B-valid), PA10 (OTG_FS_ID, device-only board), PA15, PC10, PC11 (UART escape route), PC12. They stay rea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
VDDA (pin 13) is tied to +3V3 directly - NO series resistor: VDDA is the ADC reference, an IR drop is a reference offset. C14 100 nF + C15 1 uF at the pin (DS11853 Figure 28). VSSA (pin 12) joins the ground plane at one point near the MCU.
MCU - STM32F722RET6 (MCU-1). Pin assignment per docs/aio-board-pinmap.md
Decoupling per the pin map summary: C8-C11 = one 100 nF per VDD pin (19, 32, 48, 64), each placed at its pin on the PCB. C12 = 4.7 uF bulk on 3V3 near the MCU. C13 = 100 nF on VBAT (pin 1, tied to +3V3: no coin cell, no RTC backup).
VCAP_1 (pin 30): 4.7 uF to VSS. Only VCAP pin on LQFP64, VCAP_2 is absent. VCAP_1: plain 4.7uF X5R MLCC fitted (C1779), decided 2026-08-15. DS11853 Table 19's 0.1-0.2 ohm ESR window is contradicted by ST's own practice: AN4661 calls the same part 'ceramic', every ST board fits plain MLCCs (Nucleo-6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
NRST (pin 7): 100 nF at the pin (DS11853 Figure 47). Internal pull-up 30-50k, no external one. Not 5 V tolerant (4.0 V max) - exposed on J1 pin 5.

Board: 4 copper layers, 103 parts (19 on the bottom side), 66 nets, no tracks yet.

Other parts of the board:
MH1, MH2, MH3, MH4: MountingHole_M3_3.2mm_Grommet

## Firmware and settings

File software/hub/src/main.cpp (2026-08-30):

/// @file
/// @brief hub entry point. The hub takes no arguments: it serves with its
///        built-in defaults and everything operational (the board link, the
///        tuning profiles) is driven at runtime through the websocket by the
///        pages. Anything worth deciding earlier than that is a compile-time
///        default in transport/udp_link.hpp or HubApp::Config.

#include <atomic>
#include <csignal>
#include <cstdio>

#include "hub/hub_app.hpp"
#include "log/module.hpp"
#include "log_modules.hpp"

namespace
{
    mark4::LogModule MODULE{mark4::LOG_MODULE_APP_MAIN, "app/main"};

    /// App the signal handlers stop. A file-scope pointer is the only thing a
    /// POSIX handler can reach, and requestStop() is the only thing it calls:
    /// one atomic store, nothing else.
    std::atomic<mark4::HubApp *> G_APP{nullptr};

    /// @brief SIGINT and SIGTERM handler: asks the loop to end its iteration.
    /// @param signalNumber signal received, unused
    void onStopSignal(int signalNumber)
    {
        static_cast<void>(signalNumber);
        mark4::HubApp *app = G_APP.load();
        if (app != nullptr)
        {
            app->requestStop();
        }
    }
} // namespace

int main(int argc, char **argv)
{
    static_cast<void>(argv);
    if (argc > 1)
    {
        static_cast<void>(std::fprintf(
            stderr,
            "hub takes no arguments: it serves on tcp/%u and is driven from the pages\n",
            static_cast<unsigned>(mark4::HubApp::WS_PORT)));
        return 1;
    }

    mark4::HubApp app{mark4::HubApp::Config{}};
    if (!app.init())
    {
        MODULE.error("initialization failed");
        return 1;
    }
    G_APP.store(&app);
    static_cast<void>(std::signal(SIGINT, onStopSignal));
    static_cast<void>(std::signal(SIGTERM, onStopSignal));

    MODULE.info("pages and websocket on http://127.0.0.1:%u",
                static_cast<unsigned>(mark4::HubApp::WS_PORT));

    const int code = app.run(nullptr);
    G_APP.store(nullptr);
    return code;
}

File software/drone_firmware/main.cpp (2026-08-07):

/// @file
/// @brief Firmware entry point: builds the app, runs the loop. On an init
///        failure the reason is on the RTT console and LED1 blinks fast.

#include <cstdint>

#include "firmware_app.hpp"
#include "platform_stm32/board.hpp"

namespace
{
    constexpr std::uint32_t INIT_FAILURE_BLINK_MS = 100U;
} // namespace

int main()
{
    mark4::FirmwareApp app;
    if (!app.init())
    {
        for (;;)
        {
            mark4::toggleLed1();
            mark4::delayMs(INIT_FAILURE_BLINK_MS);
        }
    }
    app.run();
}

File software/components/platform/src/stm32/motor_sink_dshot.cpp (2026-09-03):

#include "platform_stm32/motor_sink_dshot.hpp"

#include <cstddef>
#include <cstdint>

#include <stm32f405xx.h>

namespace mark4
{
    namespace
    {
        // Motor pins: PA6/PA7 = TIM3_CH1/CH2, PB0/PB1 = TIM3_CH3/CH4, all AF2.
        constexpr std::uint32_t GPIO_MODER_AF = 0x2U;     // alternate function
        constexpr std::uint32_t GPIO_OSPEED_VHIGH = 0x3U; // clean 600 kHz edges
        constexpr std::uint32_t GPIO_AF2 = 0x2U;

        // TIM3 in PWM mode 1 on the four channels, CCR preloaded (OCxPE).
        constexpr std::uint32_t TIM_CCMR_PWM1_LOW = TIM_CCMR1_OC1M_2 | TIM_CCMR1_OC1M_1 | //
                                                    TIM_CCMR1_OC1PE;
        constexpr std::uint32_t TIM_CCMR_PWM1_HIGH = TIM_CCMR1_OC2M_2 | TIM_CCMR1_OC2M_1 | //
                                                     TIM_CCMR1_OC2PE;
        constexpr std::uint32_t TIM_CCMR_PWM1 = TIM_CCMR_PWM1_LOW | TIM_CCMR_PWM1_HIGH;
        constexpr std::uint32_t TIM_CCER_ALL =
            TIM_CCER_CC1E | TIM_CCER_CC2E | TIM_CCER_CC3E | TIM_CCER_CC4E;

        // TIM3 DMA burst window: base at CCR1 (offset 0x34 / 4 = 13), four
        // transfers per request (DBL = count - 1).
        constexpr std::uint32_t TIM_DCR_BURST =
            ((DSHOT_MOTORS - 1U) << TIM_DCR_DBL_Pos) | (13U << TIM_DCR_DBA_Pos);

        // DMA1 stream 2 to TIM3_UP: channel 5, memory-to-peripheral, 16-bit,
        // memory-incrementing, single-shot (no CIRC).
        constexpr std::uint32_t DMA_CR_CONFIG = (5U << DMA_SxCR_CHSEL_Pos) | DMA_SxCR_MSIZE_0 |
                                                DMA_SxCR_PSIZE_0 | DMA_SxCR_MINC | DMA_SxCR_DIR_0;

        // Interrupt/error flags of stream 2 in the low status register.
        constexpr std::uint32_t DMA_LIFCR_STREAM2 = DMA_LIFCR_CTCIF2 | DMA_LIFCR_CHTIF2 |
                                                    DMA_LIFCR_CTEIF2 | DMA_LIFCR_CDMEIF2 |
                                                    DMA_LIFCR_CFEIF2;

        /// @brief Two-bit field write at a pin's position in a MODER-style
        ///        register (MODER, OSPEEDR).
        void setPin2(volatile std::uint32_t &reg, std::uint32_t pin, std::uint32_t value)
        {
            const std::uint32_t shift = 2U * pin;
            reg = (reg & ~(0x3U << shift)) | (value << shift);
        }

        /// @brief Four-bit alternate-function selector for a pin in AFR[0]
        ///        (pins 0-7).
        void setAfLow(volatile std::uint32_t &reg, std::uint32_t pin, std::uint32_t af)
        {
            const std::uint32_t shift = 4U * pin;
            reg = (reg & ~(0xFU << shift)) | (af << shift);
        }
    } // namespace

    void MotorSinkDshot::init()
    {
        RCC->AHB1ENR =
            RCC->AHB1ENR | RCC_AHB1ENR_GPIOAEN | RCC_AHB1ENR_GPIOBEN | RCC_AHB1ENR_DMA1EN;
        RCC->APB1ENR = RCC->APB1ENR | RCC_APB1ENR_TIM3EN;

        // PA6, PA7 -> TIM3_CH1/CH2; PB0, PB1 -> TIM3_CH3/CH4, all AF2, fast.
        setPin2(GPIOA->MODER, 6U, GPIO_MODER_AF);
        setPin2(GPIOA->MODER, 7U, GPIO_MODER_AF);
        setPin2(GPIOA->OSPEEDR, 6U, GPIO_OSPEED_VHIGH);
        setPin2(GPIOA->OSPEEDR, 7U, GPIO_OSPEED_VHIGH);
        setAfLow(GPIOA->AFR[0], 6U, GPIO_AF2);
        setAfLow(GPIOA->AFR[0], 7U, GPIO_AF2);
        setPin2(GPIOB->MODER, 0U, GPIO_MODER_AF);
        setPin2(GPIOB->MODER, 1U, GPIO_MODER_AF);
        setPin2(GPIOB->OSPEEDR, 0U, GPIO_OSPEED_VHIGH);
        setPin2(GPIOB->OSPEEDR, 1U, GPIO_OSPEED_VHIGH);
        setAfLow(GPIOB->AFR[0], 0U, GPIO_AF2);
        setAfLow(GPIOB->AFR[0], 1U, GPIO_AF2);

        // TIM3: 84 MHz timer clock straight (PSC = 0), 140-tick bit period.
        TIM3->PSC = 0U;
        TIM3->ARR = DSHOT_ARR;
        TIM3->CCMR1 = TIM_CCMR_PWM1;
        TIM3->CCMR2 = TIM_CCMR_PWM1;
        TIM3->CCER = TIM_CCER_ALL;
        TIM3->CCR1 = 0U;
        TIM3->CCR2 = 0U;
        TIM3->CCR3 = 0U;
        TIM3->CCR4 = 0U;
        TIM3->DCR = TIM_DCR_BURST;
        TIM3->DIER = TIM_DIER_UDE; // update raises a DMA request
        TIM3->CR1 = TIM_CR1_ARPE;
        TIM3->EGR = TIM_EGR_UG; // latch PSC/ARR and the zeroed CCR preloads
        TIM3->SR = 0U;
        TIM3->CR1 = TIM_CR1_ARPE | TIM_CR1_CEN; // free-running from here

        // DMA1 stream 2 addresses are fixed; only NDTR and EN are touched per
        // frame. The buffer is memory 0, TIM3's DMAR window the peripheral.
        // TIM3_UP drives DMA1 stream 2, channel 5 (RM0090 table 42): one
        // update event bursts the four CCRs through TIM3's DMAR window.
        DMA1_Stream2->CR = DMA_CR_CONFIG;
        DMA1_Stream2->PAR = reinterpret_cast<std::uint32_t>(&TIM3->DMAR);
        DMA1_Stream2->M0AR = reinterpret_cast<std::uint32_t>(m_buffer.data());
    }

    void MotorSinkDshot::push(const mark4::ActuatorFrame &frame)
    {
        // At 500 Hz the 30 us transfer is always long done; the guard only
        // matters if the loop rate ever changes.
        // TODO(tmagne): surface m_skipped (status log line) once it can occur.
        if ((DMA1_Stream2->CR & DMA_SxCR_EN) != 0U)
        {
            ++m_skipped;
            return;
        }

        m_last = frame;
        for (std::size_t motor = 0U; motor < DSHOT_MOTORS; ++motor)
        {
            const std::uint16_t value = dshotThrottle(frame.motor[motor]);
            const std::uint16_t encoded = dshotFrame(value, false);
            dshotExpand(encoded, &m_buffer[motor], DSHOT_MOTORS);
        }

        DMA1->LIFCR = DMA_LIFCR_STREAM2;
        DMA1_Stream2->NDTR = DSHOT_BUFFER;
        DMA1_Stream2->CR = DMA_CR_CONFIG | DMA_SxCR_EN;
    }
} // namespace mark4

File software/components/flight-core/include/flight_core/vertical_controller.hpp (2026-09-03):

#pragma once

/// @file
/// @brief Vertical velocity to collective command controller.

#include "flight_core/types.hpp"
#include "telemetry/registry.hpp"

namespace mark4
{
    /// Tracks a vertical velocity setpoint with a PI loop around a hover
    /// feedforward, and produces the collective motor command the mixer
    /// spreads over the four motors.
    class VerticalController
    {
      public:
        /// Default collective producing about one weight of thrust on the
        /// simulated airframe. A calibration knob by nature: the real
        /// airframe will have its own value, and the integrator absorbs
        /// what the guess misses.
        static constexpr float DEFAULT_HOVER_COLLECTIVE = 0.52f;

        /// Default proportional gain [collective per m/s]: about 4 rad/s of
        /// velocity loop bandwidth on the simulated airframe.
        static constexpr float DEFAULT_KP = 0.1f;

        /// Default integral gain [collective per m].
        static constexpr float DEFAULT_KI = 0.05f;

        /// Clamp on the integrator's contribution to the output.
        static constexpr float INTEGRAL_LIMIT = 0.2f;

        /// @param hoverCollective feedforward collective at hover [0, 1]
        /// @param kp proportional gain [collective per m/s]
        /// @param ki integral gain [collective per m]
        explicit VerticalController(float hoverCollective = DEFAULT_HOVER_COLLECTIVE,
                                    float kp = DEFAULT_KP,
                                    float ki = DEFAULT_KI)
            : m_hoverCollective(hoverCollective),
              m_kp(kp),
              m_ki(ki)
        {
        }

        /// @brief Sets the hover feedforward collective. Callable between two
        ///        steps; the integrator state is deliberately preserved so a
        ///        retune does not kick the loop.
        /// @param hoverCollective feedforward collective at hover [0, 1]
        void setHoverCollective(float hoverCollective)
        {
            m_hoverCollective = hoverCollective;
        }

        /// @brief Sets the proportional gain. Callable between two steps; the
        ///        integrator state is deliberately preserved so a retune does
        ///        not kick the loop.
        /// @param kp proportional gain [collective per m/s]
        void setKp(float kp)
        {
            m_kp = kp;
        }

        /// @brief Sets the integral gain. Callable between two steps; the
        ///        integrator state is deliberately preserved so a retune does
        ///        not kick the loop.
        /// @param ki integral gain [collective per m]
        void setKi(float ki)
        {
            m_ki = ki;
        }

        /// @return feedforward collective at hover [0, 1]
        [[nodiscard]] float hoverCollective() const
        {
            return m_hoverCollective;
        }

        /// @brief Advances the loop by one step.
        /// @param setpointMps vertical velocity setpoint, positive up [m/s]
        /// @param verticalVelocityMps estimated vertical velocity [m/s]
        /// @param dt integration step [s]
        /// @return collective command [0, 1]
        float update(float setpointMps, float verticalVelocityMps, float dt);

        /// @brief Clears the integrator (disarmed on the ground).
        void reset();

      private:
        float m_hoverCollective; ///< feedforward collective at hover
        float m_kp;              ///< proportional gain [collective per m/s]
        float m_ki;              ///< integral gain [collective per m]
        float m_integral = 0.0f; ///< integrator state

        // What the last update() computed, for the telemetry registry.
        float m_setpointMps = 0.0f; ///< vertical velocity asked for [m/s]
        float m_measuredMps = 0.0f; ///< vertical velocity estimate used [m/s]
        float m_errorMps = 0.0f;    ///< setpoint - measurement [m/s]
        float m_pTerm = 0.0f;       ///< proportional contribution
        float m_output = 0.0f;      ///< collective returned, clamped [0, 1]

        TelemetryEntry m_setpointEntry{"vertical/setpoint", TelemetryUnit::M_PER_S, m_setpointMps};
        TelemetryEntry m_measuredEntry{
            "vertical/measurement", TelemetryUnit::M_PER_S, m_measuredMps};
        TelemetryEntry m_errorEntry{"vertical/error", TelemetryUnit::M_PER_S, m_errorMps};
        TelemetryEntry m_pEntry{"vertical/p_term", TelemetryUnit::UNITLESS, m_pTerm};
        TelemetryEntry m_iEntry{"vertical/i_term", TelemetryUnit::UNITLESS, m_integral};
        TelemetryEntry m_outputEntry{"vertical/output", TelemetryUnit::UNITLESS, m_output};
    };
} // namespace mark4

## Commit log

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2026-08-04 feat(platform): stream sensor and actuator frames over UDP in the sim variant
    Replace the self-generating stubs with a real transport: UdpLink (RAII
    POSIX socket, receive timeout, reply to last sender) feeds SensorSourceSim,
    MotorSinkSim answers the simulator and TelemetrySenderSim broadcasts for
    real. The drone_sim composition root opens the sockets in init(), caps the
    run on a frame budget and stops after 2 s of silence. Packed wire structs
    are copied field-by-field at offsetof positions: taking references to
    their misaligned array members is undefined behaviour (caught by UBSan).
    Loopback unit tests cover decode, rejection and the actuator reply.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
    [drone_sim_app.cpp, main.cpp, motor_sink_sim.cpp]
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2026-08-05 feat(blackbox): record every step to a file in drone_sim
    flight-core gains a Blackbox recorder serializing each step (sensor
    frame in, actuator frame out) into a packed, versioned, fixed-size
    record handed to the AbsLogSink service. The sim variant provides
    LogSinkFile, which appends records to logs/drone_sim.m4bb and flushes
    every 64 writes so a run killed under the debugger still leaves a
    usable log. drone_sim wires both in and reports the record count on
    exit.
    [drone_sim_app.cpp, main.cpp]
2026-08-05 feat(drone_sim): write one timestamped blackbox file per run
    The single fixed path was truncated at every start, so each run
    destroyed the previous log. The composition root now stamps the file
    name with the wall clock (logs/drone_sim_YYYYMMDD_HHMMSS.m4bb).
    [drone_sim_app.cpp]
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2026-08-05 feat(flight-core): estimate the attitude with a Mahony filter
    Quaternion attitude from gyro integration plus a PI correction toward
    the gravity direction, which also estimates the constant gyro bias.
    The correction is gated on the accelerometer norm around 1 g: in free
    fall, during the throw thrust and on impacts the estimator falls back
    to pure gyro integration. Timestamp gaps re-arm the integration step
    instead of being integrated. Estimation keeps running while the kill
    switch is engaged, so the attitude is fresh on release.
    drone_replay prints the final attitude and bias, making a replayed
    log the quickest way to exercise the estimator on real data.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
    [main.cpp]
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2026-08-05 feat(flight-core): fuse baro and accel into a vertical estimate
    Complementary filter: the specific force is rotated into the world
    frame with the estimated attitude and integrated for the short term,
    the barometric altitude corrects the long term. Free fall needs no
    special case - 0 g in, the velocity slope comes out at -g. The
    altitude is relative to a baro reference averaged at startup, and
    drone_replay reports the final vertical state.
    [main.cpp]
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2026-08-05 feat(flight-core): detect the throw and predict the apex
    ThrowDetector requires the complete signature, in order: a sustained
    thrust phase above 2 g, then free fall below 0.3 g confirmed for
    50 ms. A drop without thrust, a short bump, a hand carry or a release
    slower than a real throw never detect - the safety gate before
    anything ever spins. The release velocity is read from the vertical
    estimator at the instant the specific force vanishes, and the apex is
    predicted from it, never detected after the fact:
    t_apex = t_release + vz0 / g. drone_replay reports the detections.
    [main.cpp]
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2026-08-05 fix(drone_sim): flush the throw announcement immediately
    stdout is fully buffered when piped (VS Code debug console, files):
    the detection line only appeared at process exit, or never on a kill.
    [drone_sim_app.cpp]
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2026-08-05 feat(flight-core): safety cutoff on impact, saturation and lost attitude
    Playing with mid-flight throws exposed the dangerous path: a crash
    with a corrupted attitude estimate sends the vertical estimate off by
    tens of meters, and the hover stack answers with full throttle on the
    ground. The motors are now cut and latched when the accel norm spikes
    above 8 g (impact), the gyro norm nears its full scale, or the
    estimated tilt stays beyond 75 deg - the hover stack could only push
    the drone into the ground from there. Lowering the stick rearms.
    drone_sim announces the cutoff on its console.
    [drone_sim_app.cpp]
2026-08-06 feat(flight-core): fly the full throw sequence into a braked hover
    An arm switch gates a new flight state machine: armed motors off,
    ballistic coast once the throw is detected, spin-up ahead of the
    predicted apex, tilt recovery at a fixed collective, then an altitude
    hold that briefly leans against the dead reckoned momentum of the
    throw. The braking is one-shot: once the estimate is spent it rebuilds
    from its own bias, not from motion, so the drone levels for good.
    Raising the stick hands over to stick flight; the safety cutoff stays
    latched until both controls are released.
    Estimator hardening, each point learned from a logged failure:
    - Mahony's accel correction is suspended during delib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
    [drone_sim_app.cpp, telemetry.cpp]
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2026-08-06 feat(protocol): scriptable simulator pair (wire version 9)
    Everything a scripted campaign needs to drive the real simulator:
    - The actuator packet echoes the timestamp of the sensor packet it
    answers, and the flight core stamps its outputs accordingly. This is
    the lockstep handshake: the simulator can wait for the reply to the
    exact tick it sent and resend on packet loss, instead of accepting
    whatever arrives.
    - A scenario command packet (reset, RC state, instant throw, full hand
    throw sequence) on its own UDP port, listened to by the simulator.
    - drone_sim takes --sim-port and --telemetry-port so several instances
    run side by side; the telemetry mirror follows on port + 2.
    Co-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
    [drone_sim_app.cpp, main.cpp, motor_sink_sim.cpp]
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2026-08-07 feat(platform): stm32 board bring-up - clock, RTT console, I2C scan
    Real drivers for the mark1 board, registers written by hand from RM0090:
    - board: 168 MHz from the 8 MHz crystal through the main PLL (HSI
    fallback kept alive for logging), DWT-based delayMs, status LEDs
    - rtt: hand-written SEGGER RTT control block, non-blocking up buffer,
    printf-style logging through newlib-nano vsnprintf
    - i2c_bus: blocking 100 kHz I2C1 master on PB8/PB9, poll-with-timeout
    everywhere so a stuck bus fails transfers instead of hanging the loop
    The firmware app becomes the bring-up program: clock report, I2C scan
    of the sensor breakout, 1 Hz heartbeat. Verified on hardware: 0x68
    (MPU6050) and 0x77 (ba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
    [board.cpp, main.cpp]
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2026-08-07 feat(firmware): timer-paced flight loop on real hardware
    The flight core now steps at 500 Hz on target, fed by real IMU data:
    - startup.c: vector table extended to the peripheral IRQs (through
    TIM3), weak-aliased handlers
    - ClockStm32: TIM2 free-running at 1 MHz, 64-bit microseconds
    - SensorSourceStm32: TIM3 update interrupt paces the loop, WFI between
    ticks, IMU burst per tick, overrun and read-failure counters; an I2C
    glitch reuses the previous sample instead of stopping the loop
    - I2C1 moves to 400 kHz fast mode: a 14-byte burst at 100 kHz would
    eat 1.5 ms of the 2 ms frame budget
    - MotorSinkNull: no ESC wired, keeps the last frame for status logs
    - FirmwareApp: composition root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
    [firmware_app.cpp, main.cpp, sensor_source_stm32.cpp]
2026-08-07 feat(platform): MS5611 driver, I2C bus recovery, faulty cell gated
    Ms5611: PROM calibration with the AN520 CRC-4 check, non-blocking
    conversion state machine at OSR 4096 pumped once per frame tick (one
    pressure/temperature solution every 10 ticks), datasheet first and
    second order compensation in 64-bit integer math.
    I2cBus::init() now recovers a bus left hanging by an MCU reset that
    cut a transaction short: SCL hand-clocked as GPIO until the slave
    releases SDA, then a manual STOP. A debugger resetting mid-transfer
    made this a hard requirement, SWRST alone cannot free the line.
    The MS5611 on this GY-86 is faulty or counterfeit: the protocol is
    byte-perfect (valid PROM CRC, a second ADC rea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
    [firmware_app.cpp, sensor_source_stm32.cpp]
2026-08-07 feat(firmware): telemetry over UART1 through the FTDI
    The board now streams the same TelemetryPacket the simulator broadcasts
    over UDP, at 50 Hz on UART1 (PB6/PB7, 115200 baud):
    - protocol/serial_framing.hpp: sync pair + length + XOR checksum around
    each packet, because a UART stream has no datagram boundaries; header
    only, with an incremental parser for receivers and unit tests
    - TelemetrySenderStm32: USART1 with a fully interrupt-driven transmit
    ring; send() only copies bytes, a packet that does not fit is dropped
    whole so frames stay self-consistent
    - vector table extended to USART1 (position 37)
    - tools/telemetry/read_serial.py: PC-side decoder, stdlib only
    Verified on hardware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
    [firmware_app.cpp]
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2026-08-07 feat(firmware): status LED policy, everything through LED1
    LED2 never lights on this unit (PC14 measures 3.3 V on IDR when
    driven): all the signalling goes through LED1, documented in
    docs/bring-up.md. One pattern at a time over a one second cycle of
    20 slots, the flight state has priority and health only shows while
    idle: short flash when idle and healthy, double flash when a health
    counter moved during the last window, 2 Hz when armed, solid when the
    motors are commanded or imminent, 5 Hz on a latched cutoff (distinct
    from the continuous 10 Hz of a failed init).
    [board.cpp, firmware_app.cpp, status_leds.cpp]
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2026-08-07 feat(firmware): RC uplink with fail-safe; a kill ends the mission
    The USART1 transport moves to a shared uart1 module (transmit and
    receive rings behind one interrupt) so the telemetry sender and the
    new CommandReceiverStm32 sit on the same full-duplex link. The app
    merges the received pilot state into every SensorFrame, with a 500 ms
    fail-safe: silence on the uplink reverts to kill engaged and disarmed,
    so the safe state is the default, not an action.
    In the core, the kill switch now also returns the state machine to
    IDLE: releasing it never resumes an armed or flying phase on its own,
    flying again takes a deliberate rearm. The LED shows the lock as a
    third short flash (one healthy, two de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
    [firmware_app.cpp, status_leds.cpp]
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2026-08-07 feat(firmware): NVIC system reset on the reboot command
    systemReset() writes AIRCR (VECTKEY plus SYSRESETREQ) behind a data
    barrier and parks in WFI until the asynchronous reset lands; the app
    triggers it on a valid RebootCommandPacket from the uplink. The whole
    chip restarts through the reset vector, and the I2C bus recovery
    absorbs the transaction the reset cuts short.
    Validated on the board: reboot command sent over UDP through the
    bridge, telemetry uptime dropped from 142.8 s to 1.5 s.
    [board.cpp, firmware_app.cpp]
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2026-08-09 feat(platform): waitFrame becomes tri-state and drone_sim fails on empty runs
    AbsSensorSource::waitFrame returned one bool with three meanings:
    'exhausted' per the interface, '2 s idle' in the sim source, 'never
    happens' on stm32 - and the two apps reacted in opposite ways. The
    result is now explicit: FRAME, TIMEOUT (transient, the caller owns the
    retry policy) or EXHAUSTED (final). The sim source reports TIMEOUT, the
    replay source EXHAUSTED at end of file, the timer-paced stm32 source
    only ever FRAME. drone_sim now exits nonzero when no sensor packet ever
    arrived, so a batch run that never connected can no longer look green.
    Claude-Ses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
    [drone_sim_app.cpp, firmware_app.cpp, main.cpp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]
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2026-08-09 fix(firmware): honor the declaration-order init promise, document stm32 constraints
    FirmwareApp::init initialized the bus, IMU and barometer before m_clock
    although the class promises declaration-order initialization - the
    pattern's value is that the promise is mechanical, so the clock now
    starts first. The three undocumented constraints of the stm32 services
    are now stated where they bite: the accepted WFI wake race (one 2 ms
    hiccup, counted as an overrun, never a lost tick), the nowUs()
    single-context and once-per-wrap requirements, and the single-instance
    coupling of the TIM3 tick counter.
    Claude-Session: https://claude.ai/code/sessi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
    [firmware_app.cpp, sensor_source_stm32.cpp]
2026-08-09 refactor(platform): one TelemetryPublisher shared by every composition
    sendTelemetry() was byte-identical in drone_sim and drone_replay, the
    firmware carried a third copy of the pack-and-send block, and the
    decimation factor 10 lived in all three apps with two different counter
    schemes (stepCount vs local counter) that had already drifted.
    platform/src/common/ receives its first promised composed helper: a
    TelemetryPublisher owning the counter and the factor, used by the three
    compositions.
    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
    [drone_sim_app.cpp, firmware_app.cpp]
2026-08-09 fix(ci): clang-tidy covers the stm32 sources
    The tidy job only ever saw the desktop compile database, so the ~17
    register-level driver sources - the code most in need of bugprone-*
    checks - had zero static analysis. scripts/tidy_stm32.sh runs clang-tidy
    over the stm32 database, feeding clang the arm-none-eabi system include
    paths it cannot discover on its own. A scoped platform/src/stm32/
    .clang-tidy disables the checks that are wrong by construction on MMIO
    code (fixed-address dereference, datasheet magic numbers, static/const
    member conversion, linker-symbol globals), registers.hpp exempts the
    RM0090 register names, and the genuine findings are fixed: uninitialized
    sample and record struct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
    [firmware_app.cpp, sensor_source_stm32.cpp]
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2026-08-09 refactor(protocol): centralize the port defaults in one header
    Every UDP port default and the telemetry mirror relationship now live in
    protocol/ports.hpp; the +2 arithmetic in the sim telemetry sender is
    replaced by the shared telemetryMirrorPort() rule.
    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
    [drone_sim_app.cpp, main.cpp]
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2026-08-09 refactor(firmware): route the RC uplink through RcTracker
    The firmware loop kept its own copy of the RC state, its own last-seen
    timestamp and its own fail-safe comparison. Hand all three to the shared
    RcTracker: the poll loop now pumps the tracker (which consumes the RC
    packets) and only handles what comes back out, the reboot command; the
    frame gets its RC by graft() and the status line reads the fail-safe from
    failsafeActive() instead of a local flag.
    Behavior is byte-for-byte identical, including the banner that prints the
    fail-safe window (now RcTracker::RC_TIMEOUT_US, the same 500 ms). The
    point is that the sim compositions can now reuse the exact same code
    path instead of reimplement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
    [firmware_app.cpp]
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2026-08-09 feat(platform): announce broadcast from the flight process
    Nothing emitted the AnnouncePacket layout that shipped with the wire, so
    the ground side still had to be told by hand which ports were live. Add
    AnnouncePublisher next to its platform_common neighbors and wire it into
    drone_sim, which also gains the RC path the previous commit left it
    without: a bound command link, a CommandReceiverSim on it and the shared
    RcTracker, drained and grafted every frame.
    Grafting happens on every frame, not only when a packet arrived: the
    frame object is reused across iterations, so skipping it would carry
    stale RC forward and hide the very fail-safe this track exists to
    exercise.
    One announce per secon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
    [drone_sim_app.cpp, main.cpp]
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2026-08-09 feat(hub): udp and serial transports with stream recording
    The hub now owns resources: one poll loop drains every UDP listener and
    the board UART, routes what it decodes, and keeps the discovery table
    honest. Demultiplexing is by header everywhere, never by size.
    - UdpTransport keeps one SO_REUSEADDR listener per watched port and one
    sending socket. Ports are subscribed at runtime: the configured stream
    ports are pinned for the whole run, the ones a process announces are
    followed for as long as that process lives, refcounted by port.
    - SerialTransport is the single owner of the cable, raw termios and
    non-blocking, feeding the frame parser of protocol/. A board that
    reboots or a ca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
    [main.cpp]
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2026-08-09 feat(firmware): answer tuning requests on the rc uplink
    The board composition already handed back everything that was not RC so it
    could answer the reboot command itself; the rest now goes to a TuningService
    instead of being dropped. That closes the bring-up loop: a gain can be moved
    from the bench over the same UART the telemetry comes back on, with no
    reflash, and the ack says which value is really flying.
    The reboot check stays first: a reset is unconditional, and nothing else may
    sit between a reboot command and the reset. The RTT status line grows the
    request and answer counters, which is how a silent link tells "nobody asked"
    from "asked and refused".
    Cost on the F405: .text 20204 ->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
    [firmware_app.cpp]
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2026-08-09 feat(platform): trajectory hash and run stats for simulated runs
    A campaign could tell whether a run recovered, never whether two runs
    given the same scenario were the same run. Comparing trajectories meant
    eyeballing plots, so a determinism regression in the plant, the link or
    the core had nowhere to show up.
    SimRunTracker folds every stepped frame of a run into one FNV-1a 64 hash
    - relative timestamp, gyro, accelerometer, barometer and motors - and
    seals it at the end of a window, so two runs boil down to two numbers
    that either match or do not. The hash is defined over time RELATIVE to
    the reset that opened the run: how long the process had been up is not a
    property of the run, and two i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
    [drone_sim_app.cpp, main.cpp]
2026-08-09 feat(protocol)!: v12, scenario commands ride the lockstep link
    A batch campaign could not tell whether two runs given the same scenario
    were the same run. Scenarios went to a listening port of their own on a
    tick nobody agreed on, the plant carried state across resets (the hand's
    grab counter, the raw-stream decimation, an unseeded generator), and
    nothing measured the trajectory that came out. Reproducibility was a
    hope, not a property.
    Scenarios now ride inside the lockstep reply. The reply is the one
    datagram the handshake already guarantees delivery of - the plant resends
    its sensor packet until the answer to that exact tick arrives - so a
    scenario needs no acknowledgement machinery, onl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
    [drone_sim_app.cpp, main.cpp, motor_sink_sim.cpp]
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2026-08-09 feat(hub): serve static pages over HTTP on the WebSocket port
    ix::HttpServer is an ix::WebSocketServer that dispatches on the Upgrade
    header, so one port carries both the websocket and the pages. A page loaded
    from the hub reaches it back at location.host and never learns a port.
    Routing is a pure function of (method, uri): no socket, no hub state, so it
    runs on the library connection threads without a lock. A URI holding a ".."
    component is refused rather than normalized, javascript is served as
    text/javascript (anything else and a browser refuses to run an ES module),
    and every response carries Cache-Control: no-store. A missing pages
    directory is one log line and a 404 per request, never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
    [main.cpp]
2026-08-09 feat(hub): stream alignment core + live compare messages
    One join, one rule, two callers: a telemetry sample and the exact simulator
    state nearest to it describe the same instant within 30 ms, nearest wins,
    unmatched samples are dropped. The live half buffers both streams and only
    compares a sample once no exact state still to come could be nearer to it,
    so what a page shows while a session runs is what the recording of that
    session gives afterwards, pair for pair. That is what the 30 ms delay buys,
    and a test replays a recorded session through both paths to prove it.
    The scoring (RMS, worst error, worst one-second windows per metric) is
    frozen against the numbers the python implementation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
    [streams_20260805_213627_simraw.csv, streams_20260805_213627_telemetry.csv]
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2026-08-09 feat(replay): announce drone_replay to the ground side
    drone_replay broadcast telemetry but never announced itself, so hub
    discovery never saw it and a page had no name to address it by. It now
    publishes the same one-per-second AnnouncePacket every other flight
    process does, carrying a real session identity and no command port -
    nothing steers a replay.
    The session identity was drawn in drone_sim's main.cpp; it moves to
    platform_common so both composition roots draw it the same way.
    --announce-port moves the broadcast off the default port, for a hub
    started on one of its own; the argument parsing becomes a loop, so the
    options no longer have to come in one fixed order.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
    [main.cpp]
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2026-08-10 refactor(platform)!: remove the telemetry mirror port
    The mirror at telemetry + 2 (udp/47803 by default) existed for exactly one
    consumer: the Godot attitude compare view, whose sockets bind exclusively and
    could not share the telemetry broadcast. That view is gone, and every
    consumer left sets SO_REUSEADDR and reads udp/47801 directly, so the
    duplicate datagram was pure waste on every packet.
    Removed: telemetryMirrorPort() and TELEMETRY_MIRROR_PORT from the ports
    header, the second sendto in TelemetrySenderSim (its open() loses the mirror
    flag, so the announce sender no longer has to opt out), the hub rebroadcast
    of the mirror, and the python and GDScript copies of the constant. 47803 is
    l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
    [drone_sim_app.cpp, main.cpp]
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2026-08-10 feat(sim)!: build-time frame budget, a silent plant grounds the drone
    The frame count leaves the command line: a run ends with the operator or
    the link, never because a counter ran out. A finite budget is a bench or
    CI decision, so it is the DRONE_SIM_FRAME_LIMIT cmake cache variable
    (0 = no limit, the default) baked in at build time. The batch stops
    passing a budget.
    A silent plant no longer ends the run either. On a real board a dead
    sensor grounds the drone but does not reboot it, so the composition stays
    up too: waitFrame TIMEOUT becomes the 'platform not ready' state, the
    loop keeps announcing (wait granularity lowered to 500 ms to hold the
    one-per-second announce contract) and keeps d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
    [drone_sim_app.cpp, main.cpp]
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2026-08-18 feat(hardware): shrink mark4-fc to 36x36 and split assembly by side
    Board outline, connectors and assembly strategy all move in one pass;
    schematic, PCB and the fab package are propagated together.
    - Rebuild the Edge.Cuts outline at 36x36 (the floor the 30.5 mm M3
    pattern allows) and fix the four corner fillets whose arc midpoints
    sat diametrically opposite, which cut a 4 mm disc out of each corner.
    - Reduce SWD from 6 to 3 positions (SWDIO/SWCLK/GND) so SWD plus USB-C
    fit the edge budget; SWO is gone, BOOT0 stays the recovery path.
    - Move the hand-soldered parts (LDO, flash, Q1, JP1, test points and
    their pull-ups) to the bottom face; the JLCPCB package now covers the
    top side on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
    [connectors.kicad_sch, indicators.kicad_sch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]
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
